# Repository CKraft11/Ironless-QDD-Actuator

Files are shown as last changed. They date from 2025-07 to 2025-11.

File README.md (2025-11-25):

# Ironless-QDD-Actuator

## Overview

The Ironless-QDD-Actuator is a low-cost, high-torque, fully 3D-printed quasi-direct-drive actuator for robotics projects. Using a Halbach array for an ironless rotor and a 3D-printed cycloidal planetary gearbox, it delivers up to 29.4Nm of holding torque for \~$70 (with controller). All custom parts are 3D-printable, making it ideal for makers and hobbyists.

### Key Features

- **Low Cost**: \~$40 (actuator), \~$70 (with controller)
- **High Torque**: 29.4Nm holding torque
- **Fully 3D-Printed**: No machining required
- **Ironless Rotor**: Halbach array for high efficiency
- **Zero Backlash**: Cycloidal gearbox for precision

## Documentation

For detailed design, assembly, and testing info, see my blog post:\
https://cadenkraft.com/ironless-cycloidal-planetary-actuator/

## Repository Contents

- CAD files for entire actuator
- FEMM simulation files
- Bill of Materials (BOM)
- ODrive configuration for MKS X Drive

## Assembly Tips

- USE ENGINEERING PLASTICS! (PA6-GF, PA6-CF, PET-CF, etc) Using PLA is tempting but the rotor will definilty creep due to the magnetic forces.
- Rotor specifically needs to be printed @ 100% infill using a high stiffness plastic with low creep
- Using "CF-Core" filaments for the gears is untested but should work amazingly for having the smooth non abrasive plastic on the outside but still having the stiff carbon additives for strength
- M3 Tap is needed for assembling the planet carrier
- Lithium grease should be used inside the gearbox assembly

## License

MIT License

Permission is hereby granted, free of charge, to any person obtaining a copy of this project and associated files to use, copy, modify, merge, publish, distribute, sublicense, and/or sell copies, provided the following notice is included:

Credit: Caden Kraft (GitHub: CKraft11)

## Contributing

Feedback and contributions are welcome! Submit issues or pull requests on GitHub. If you use this actuator, please share your project!

## Git LFS Required

This repository tracks large binary assets (e.g., `.STEP` CAD files and FEMM outputs) with Git Large File Storage (LFS). To clone and receive these files correctly, install Git LFS before cloning.

If you hit LFS bandwidth limits, the full print and CAD files are also mirrored on MakerWorld: https://makerworld.com/en/models/2042262-caden-kraft-s-qdd-cycloidal-planetary-actuator#profileId-2203426

- Install Git LFS:
  - Windows: `winget install Git.GitLFS` or install via Git for Windows installer (enable LFS component)
  - macOS: `brew install git-lfs`
  - Linux: `sudo apt-get install git-lfs` (Debian/Ubuntu) or use your distro’s package manager
- Initialize LFS once on your machine: `git lfs install`
- Clone the repo: `git clone https://github.com/CKraft11/Ironless-QDD-Actuator.git`

If you already cloned without LFS and see small pointer files instead of the actual binaries, run:

- Ensure LFS is installed: `git lfs install`
- Fetch LFS content: `git lfs fetch --all`
- Checkout LFS files: `git lfs checkout`
  - If needed to fully rehydrate files: `git rm --cached -r .` then `git reset --hard`

Notes
- You do not need to run `git lfs track` yourself; the repository already contains `.gitattributes` with the correct patterns.
- When contributing changes to large binaries, commit as usual; LFS handles storage automatically once installed.

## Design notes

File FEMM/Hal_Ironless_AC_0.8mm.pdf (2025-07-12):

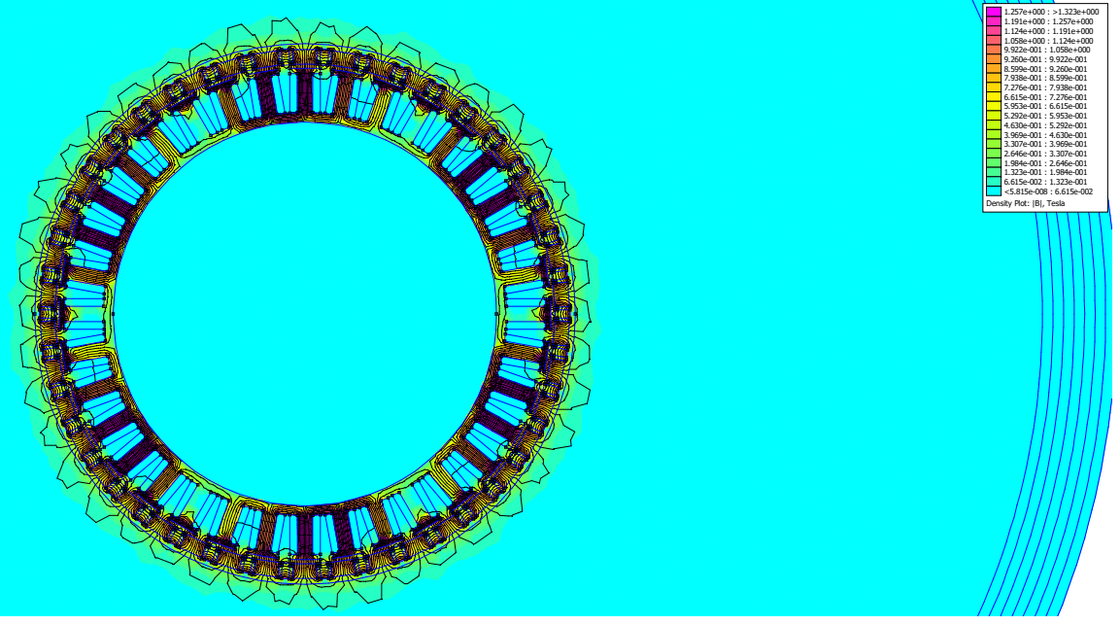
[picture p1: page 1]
Density Plot: |B|, Tesla 1.257e+000 : >1.323e+000 1.191e+000 : 1.257e+000 1.124e+000 : 1.191e+000 1.058e+000 : 1.124e+000 9.922e-001 : 1.058e+000 9.260e-001 : 9.922e-001 8.599e-001 : 9.260e-001 7.938e-001 : 8.599e-001 7.276e-001 : 7.938e-001 6.615e-001 : 7.276e-001 5.953e-001 : 6.615e-001 5.292e-001 : 5.953e-001 4.630e-001 : 5.292e-001 3.969e-001 : 4.630e-001 3.307e-001 : 3.969e-001 2.646e-001 : 3.307e-001 1.984e-001 : 2.646e-001 1.323e-001 : 1.984e-001 6.615e-002 : 1.323e-001 <5.815e-008 : 6.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

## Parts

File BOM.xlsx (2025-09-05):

QDD Actuator BOM |  |  |  |  | Pricing Calculated 4/22/25
Part Name | Part Link | Part Quantity | Cost Per (Part/Gram) | Total Part Cost | Total Cost w/ Controller
6805 Bearing | https://www.amazon.com/dp/B082PYT33D?ref=ppx_yo2ov_dt_b_fed_asin_title&th=1 | 2 | $1.29
6710 Bearing | https://www.amazon.com/dp/B0D6WCB7BP?ref=ppx_yo2ov_dt_b_fed_asin_title | 2 | $2.26 |  | Total Cost w/o Controller
Makerbase MKS XRIVE Mini | https://www.aliexpress.us/item/3256806293928426.html | 1 | $29.99
N52 12x5x3mm | https://www.aliexpress.com/item/3256805740554366.html | 42 | $0.12
N50 1/2 x 1/8 x 1/16in | https://www.magnet4sale.com/n50-1-2x1-8x1-16-neodymium-rare-earth-block-magnet/ | 42 | $0.14
0.4mm Enameled Magnet Wire | https://www.aliexpress.us/item/3256801263693830.html | 60 | $0.02
10010 Stator | https://www.aliexpress.us/item/3256804196417649.html | 1 | $17.63
5x12mm Pin | https://www.aliexpress.us/item/2255800287548941.html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 | 3 | $0.28
M2.5x12mm Countersunk | https://www.aliexpress.us/item/2251832781782755.html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 | 20 | $0.03
M2.5xL4xOD3.5 | https://www.aliexpress.us/item/3256805885174058.html | 7 | $0.03
M3xL4xOD4.2 Brass Insert | https://www.aliexpress.us/item/3256805885174058.html | 14 | $0.03
M4xL4xOD5 Brass Insert | https://www.aliexpress.us/item/3256805885174058.html | 15 | $0.03
M4x25mm Shoulder Bolt | https://www.aliexpress.us/item/3256807139256917.html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 | 1 | $0.53
M2 Locknut | https://www.aliexpress.us/item/2251832612458814.html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 | 4 | $0.06
M3x6mm | https://www.aliexpress.us/item/3256803988371203.html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 | 8 | $0.04
M4 Locknut | https://www.aliexpress.us/item/2251832612458814.html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 | 1 | $0.04
M2x25mm | https://www.aliexpress.us/item/2251832782168715.html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 | 4 | $0.03
5x14x5mm Bearing | https://www.aliexpress.us/item/3256807482131308.html | 6 | $0.32

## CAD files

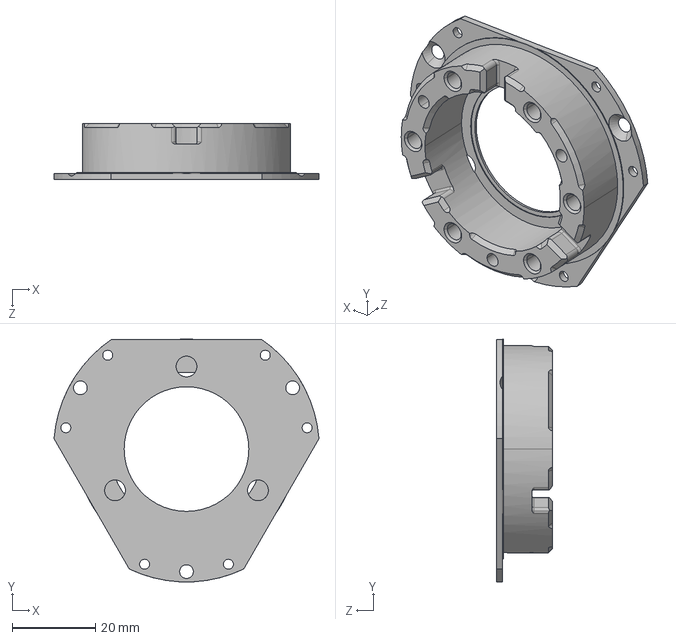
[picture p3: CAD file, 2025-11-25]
CAD/Print_Files/1x_carrier_bottom_output.STEP
63.8 x 58.5 x 13.5 mm

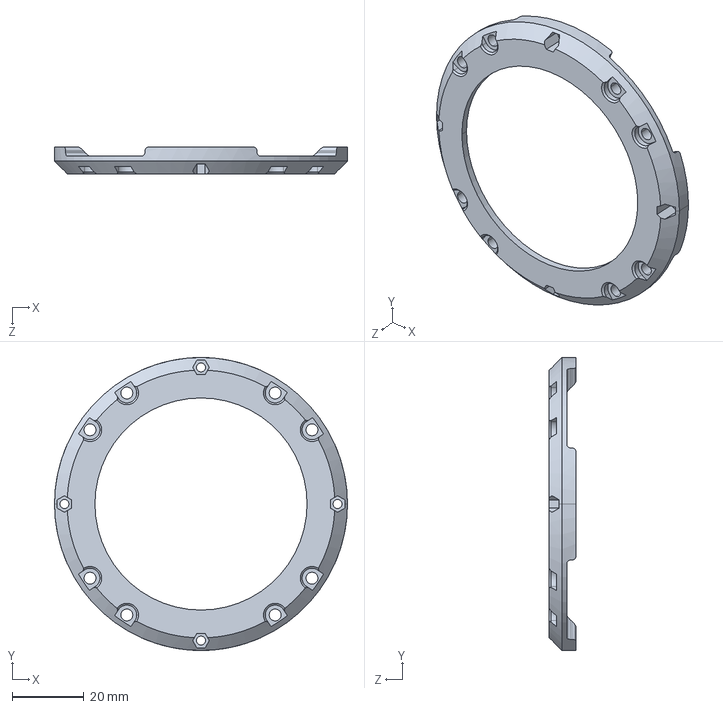
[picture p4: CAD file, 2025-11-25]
CAD/Print_Files/1x_gearbox_top.STEP
81.5 x 81.5 x 7.40 mm

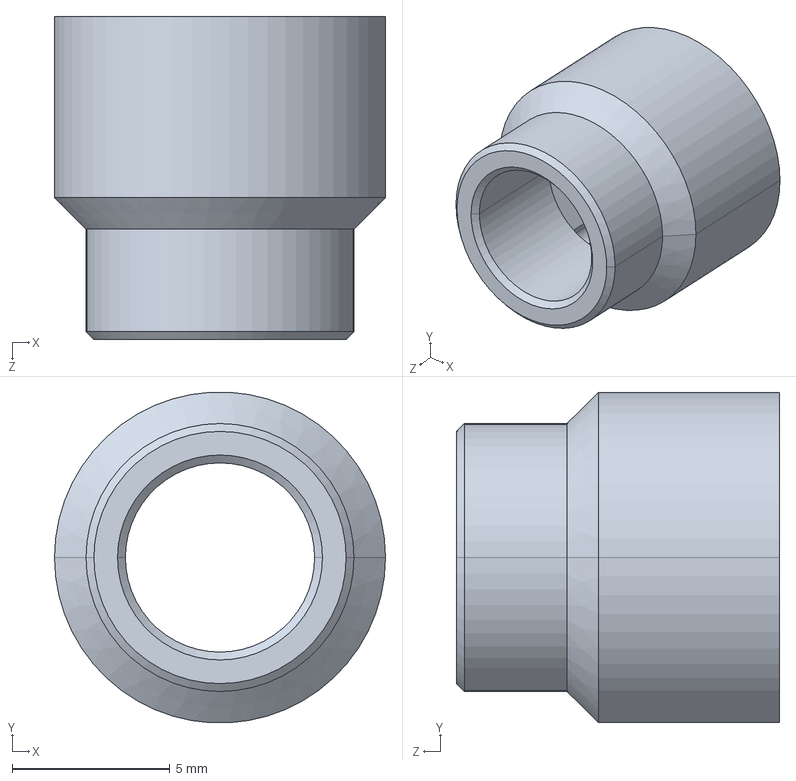
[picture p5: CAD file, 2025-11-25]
CAD/Print_Files/1x_hal_magnet_holder.STEP
10.5 x 10.5 x 10.2 mm

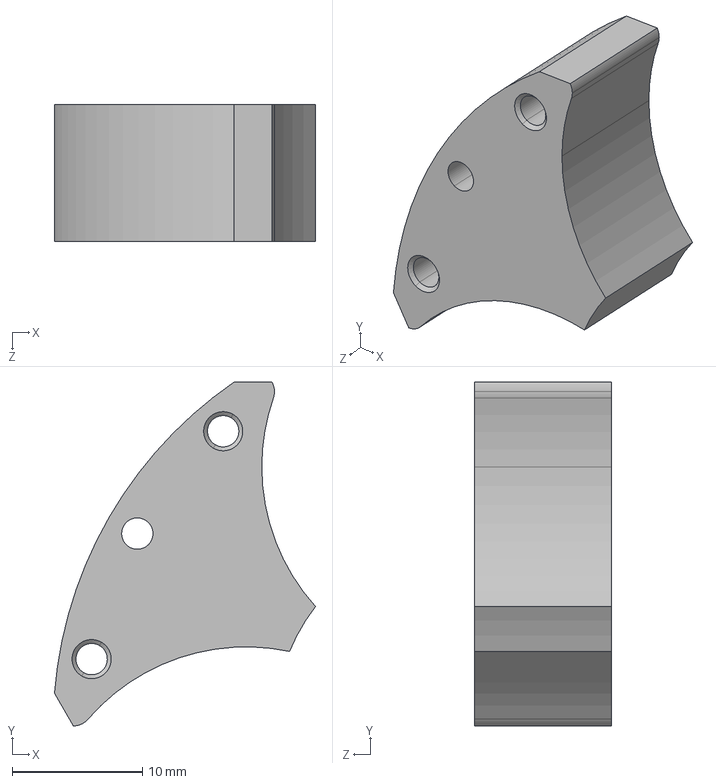
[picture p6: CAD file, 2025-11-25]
CAD/Print_Files/3x_carrier_spacer.STEP
20.0 x 26.4 x 10.5 mm

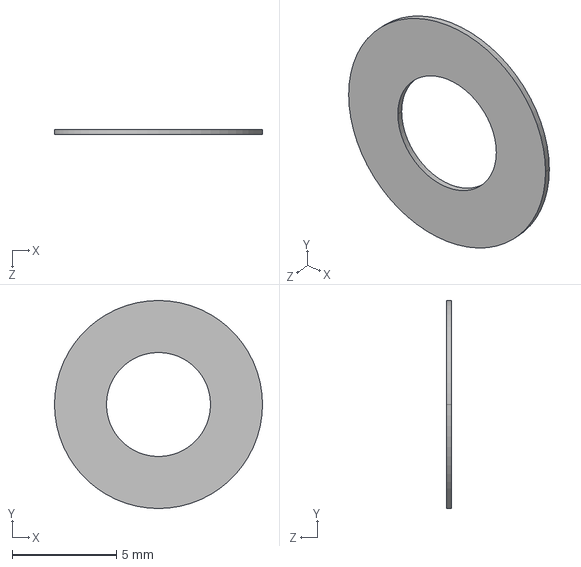
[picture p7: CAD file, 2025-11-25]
CAD/Print_Files/6x_planet_pin_spacer.STEP
10.0 x 10.0 x 0.25 mm

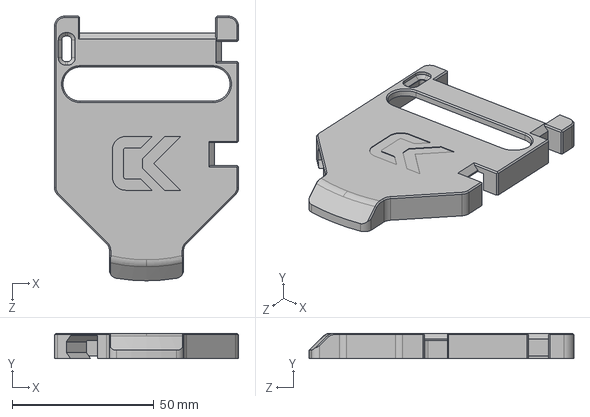
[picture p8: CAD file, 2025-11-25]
CAD/Print_Files/1x_controller_case.STEP
65.0 x 9.00 x 93.5 mm

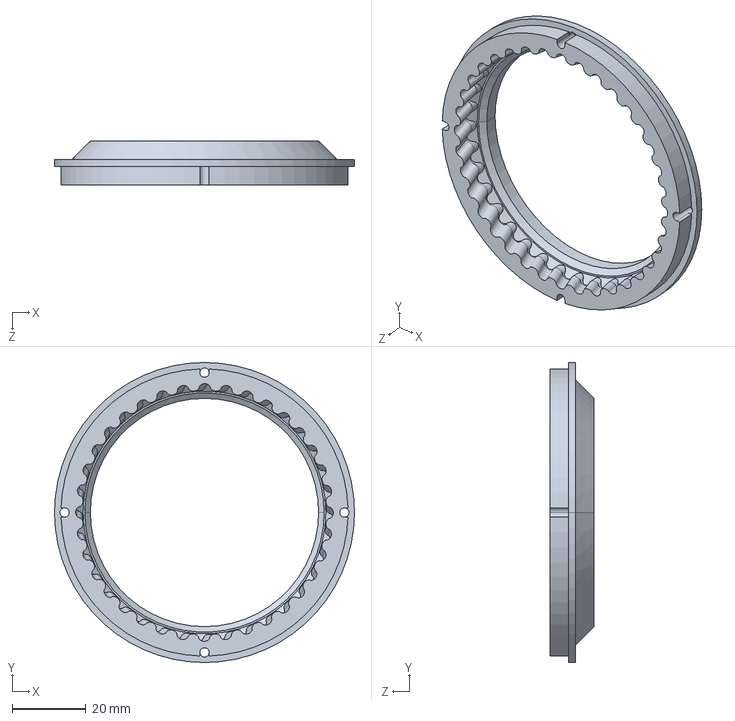
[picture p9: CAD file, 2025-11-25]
CAD/Print_Files/1x_ring_gear_bottom.STEP
81.5 x 81.5 x 12.0 mm

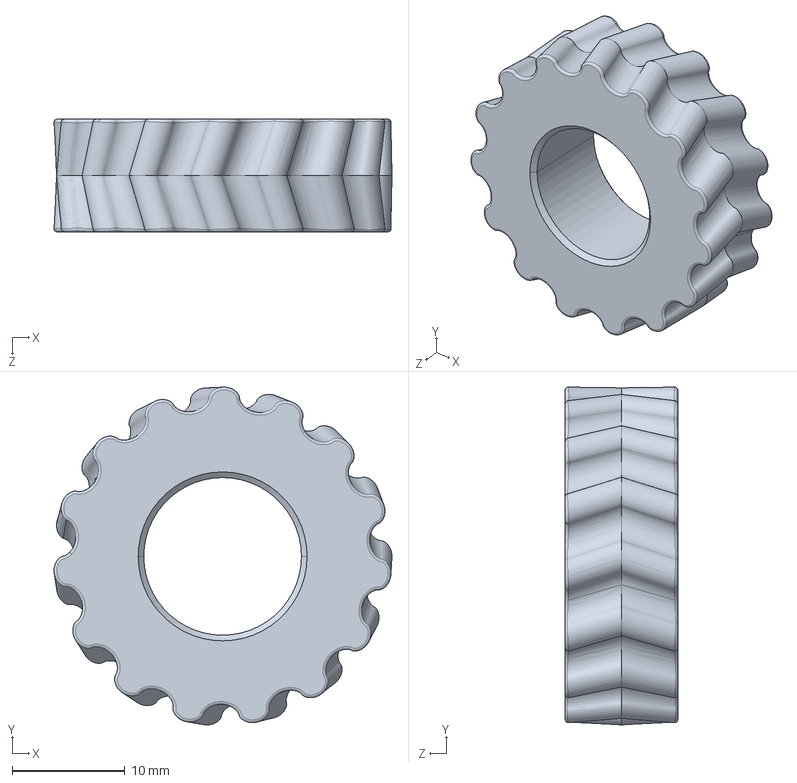
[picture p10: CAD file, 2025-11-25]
CAD/Print_Files/3x_planet_gear.STEP
30.0 x 30.0 x 10.0 mm

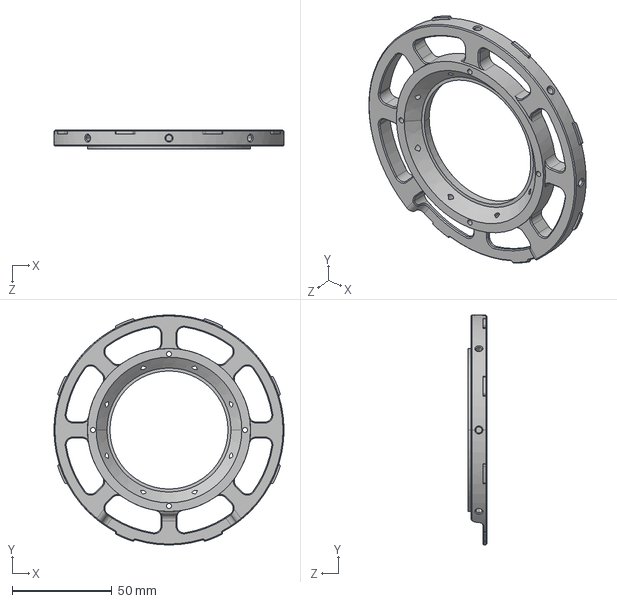
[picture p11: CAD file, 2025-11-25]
CAD/Print_Files/1x_gearbox_bottom.STEP
115.0 x 115.0 x 9.40 mm

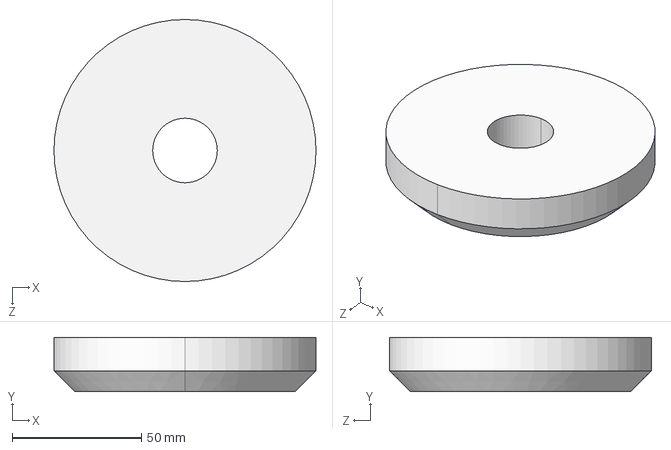
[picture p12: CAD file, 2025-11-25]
CAD/Print_Files/1x_rotor_magnet_glue_fixture.STEP
101.4 x 21.0 x 101.4 mm

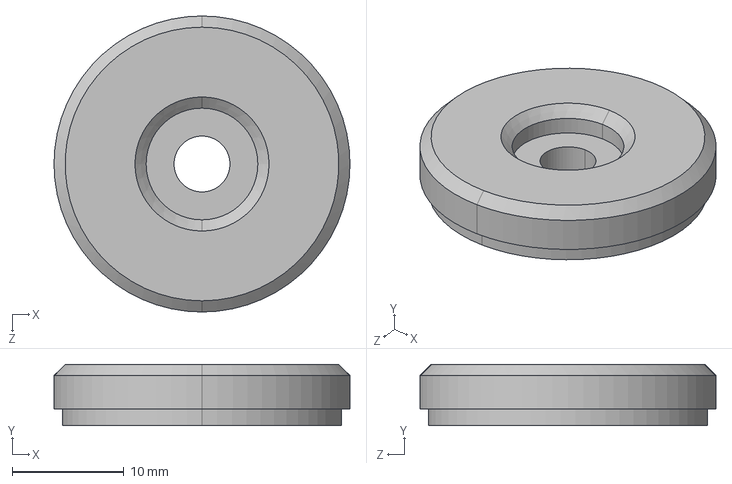
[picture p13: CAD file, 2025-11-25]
CAD/Print_Files/1x_rotor_endcap.STEP
26.5 x 5.50 x 26.5 mm

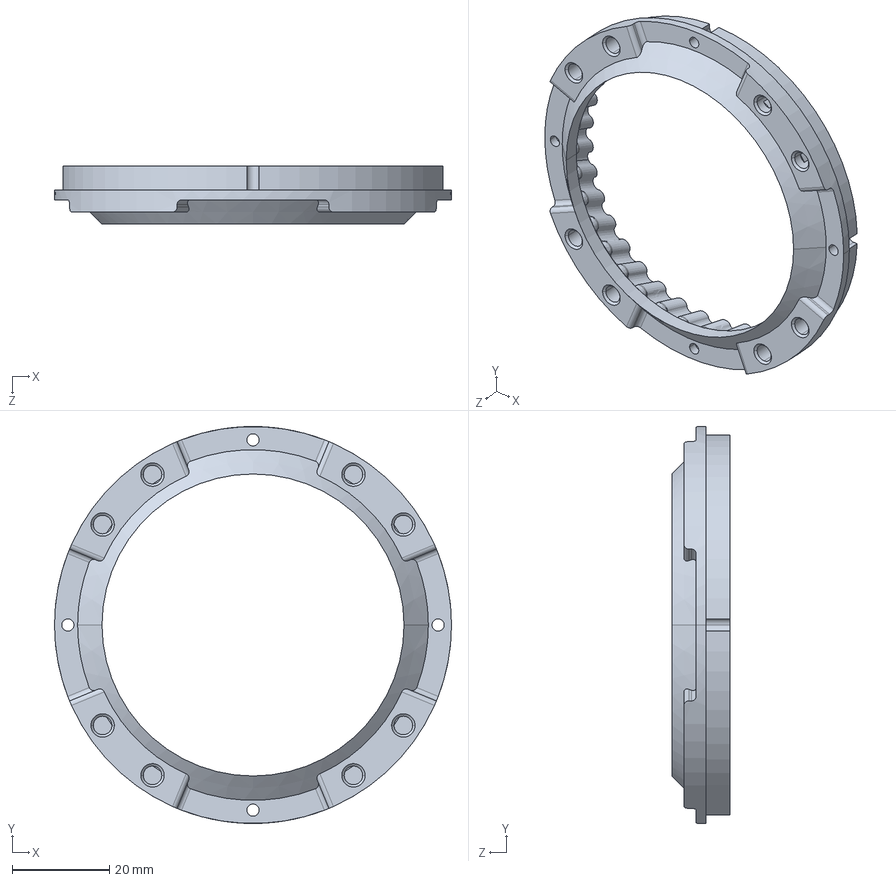
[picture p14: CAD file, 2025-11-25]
CAD/Print_Files/1x_ring_gear_top.STEP
81.5 x 81.5 x 12.0 mm

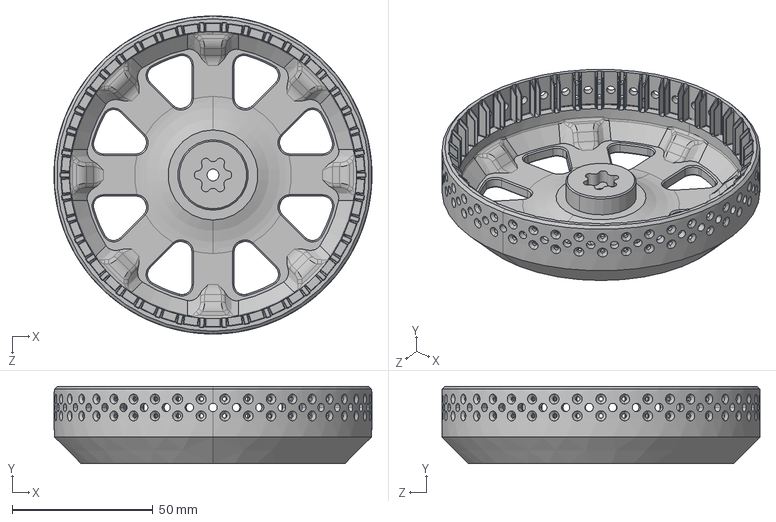
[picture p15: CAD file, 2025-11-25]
CAD/Print_Files/1x_rotor.STEP
113.0 x 27.5 x 113.0 mm

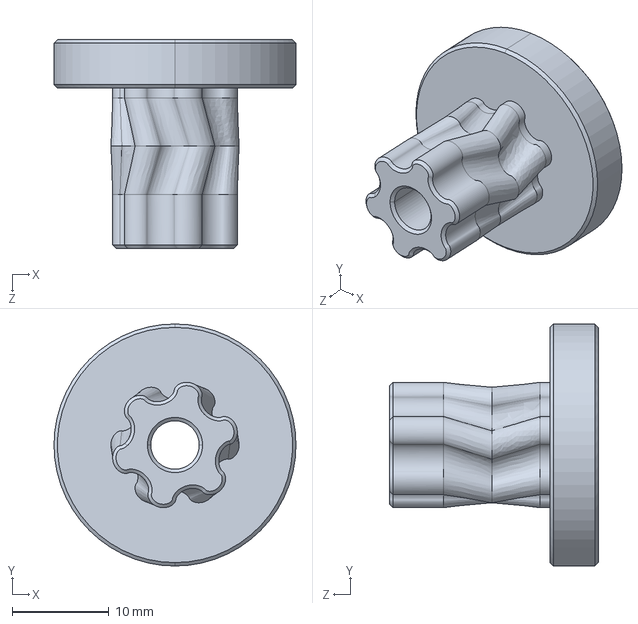
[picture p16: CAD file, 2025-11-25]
CAD/Print_Files/1x_sun_gear.STEP
25.0 x 25.0 x 21.6 mm

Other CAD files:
CAD/actuator.STEP
CAD/Print_Files/1x_carrier_top_cover.STEP
CAD/Print_Files/1x_outer_case.STEP

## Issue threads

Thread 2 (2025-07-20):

Alternative magnet sizing / relevance and/or other providers

alexbarcelo, 2025-07-20:
The project is awesome, very detailed and gives clear steps and clear directions. I am eager to jump into it.

However, I realized that there are two different magnet sizings and one of them cannot longer be found on AliExpress while the other is a US provider that might be challenging to order from.

Looking into alternatives, I found a lot of 20x#x# magnet sizing and some 15x#x#. Virtually no 12x#x# sizing found online (the one this project asks for). I haven't found any listing that has the exact same other two dimensions (I was thinking on a possible Z scaling and using longer magnets, but that can only be done with exact match on the other two dimensions).

Does anybody know of providers that stock the dimensions in the BOM? Alternatively, how easy is it (and how critical on the performance of the motor is) to retrofit/shoehorn other magnets? Maybe some 10x#x# could fit in? However, I still haven't found an exact match on the other dimensions, and those magnet might be too small, I don't know.

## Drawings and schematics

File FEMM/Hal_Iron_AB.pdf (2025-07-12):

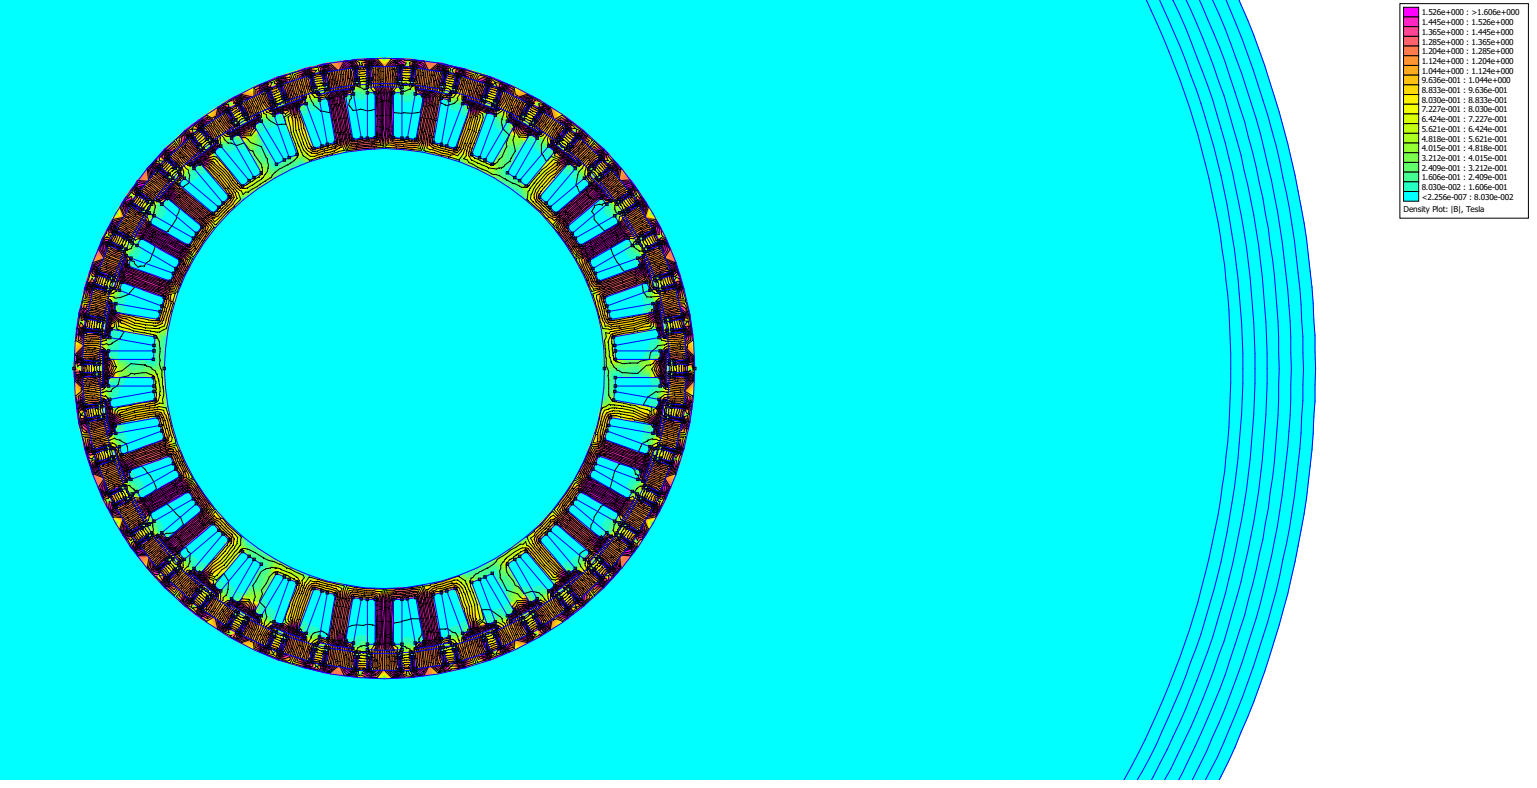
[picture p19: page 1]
Density Plot: |B|, Tesla 1.526e+000 : >1.606e+000 1.445e+000 : 1.526e+000 1.365e+000 : 1.445e+000 1.285e+000 : 1.365e+000 1.204e+000 : 1.285e+000 1.124e+000 : 1.204e+000 1.044e+000 : 1.124e+000 9.636e-001 : 1.044e+000 8.833e-001 : 9.636e-001 8.030e-001 : 8.833e-001 7.227e-001 : 8.030e-001 6.424e-001 : 7.227e-001 5.621e-001 : 6.424e-001 4.818e-001 : 5.621e-001 4.015e-001 : 4.818e-001 3.212e-001 : 4.015e-001 2.409e-001 : 3.212e-001 1.606e-001 : 2.409e-001 8.030e-002 : 1.606e-001 <2.256e-007 : 8.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

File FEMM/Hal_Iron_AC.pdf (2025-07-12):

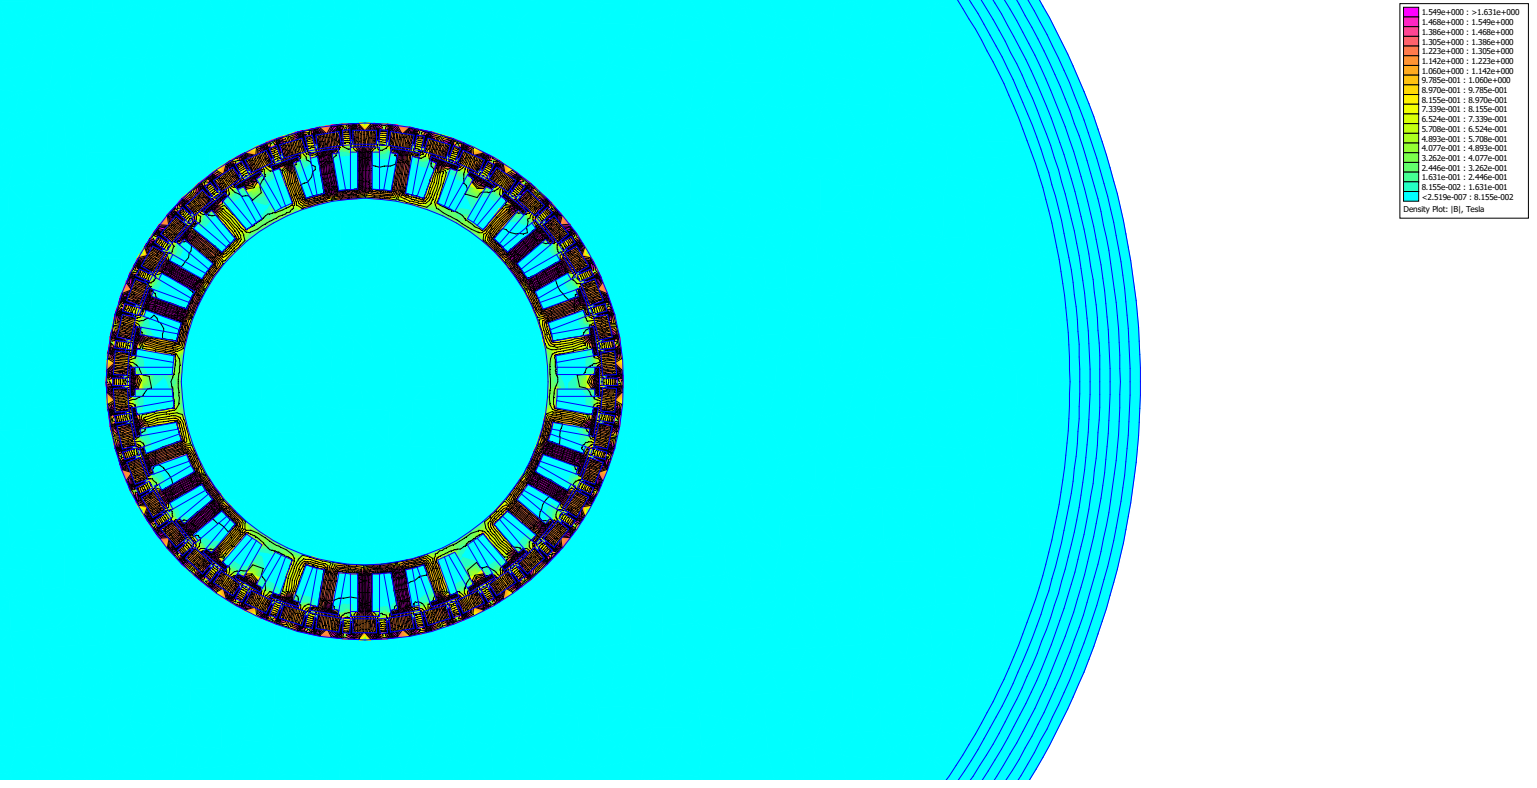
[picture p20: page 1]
Density Plot: |B|, Tesla 1.549e+000 : >1.631e+000 1.468e+000 : 1.549e+000 1.386e+000 : 1.468e+000 1.305e+000 : 1.386e+000 1.223e+000 : 1.305e+000 1.142e+000 : 1.223e+000 1.060e+000 : 1.142e+000 9.785e-001 : 1.060e+000 8.970e-001 : 9.785e-001 8.155e-001 : 8.970e-001 7.339e-001 : 8.155e-001 6.524e-001 : 7.339e-001 5.708e-001 : 6.524e-001 4.893e-001 : 5.708e-001 4.077e-001 : 4.893e-001 3.262e-001 : 4.077e-001 2.446e-001 : 3.262e-001 1.631e-001 : 2.446e-001 8.155e-002 : 1.631e-001 <2.519e-007 : 8.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

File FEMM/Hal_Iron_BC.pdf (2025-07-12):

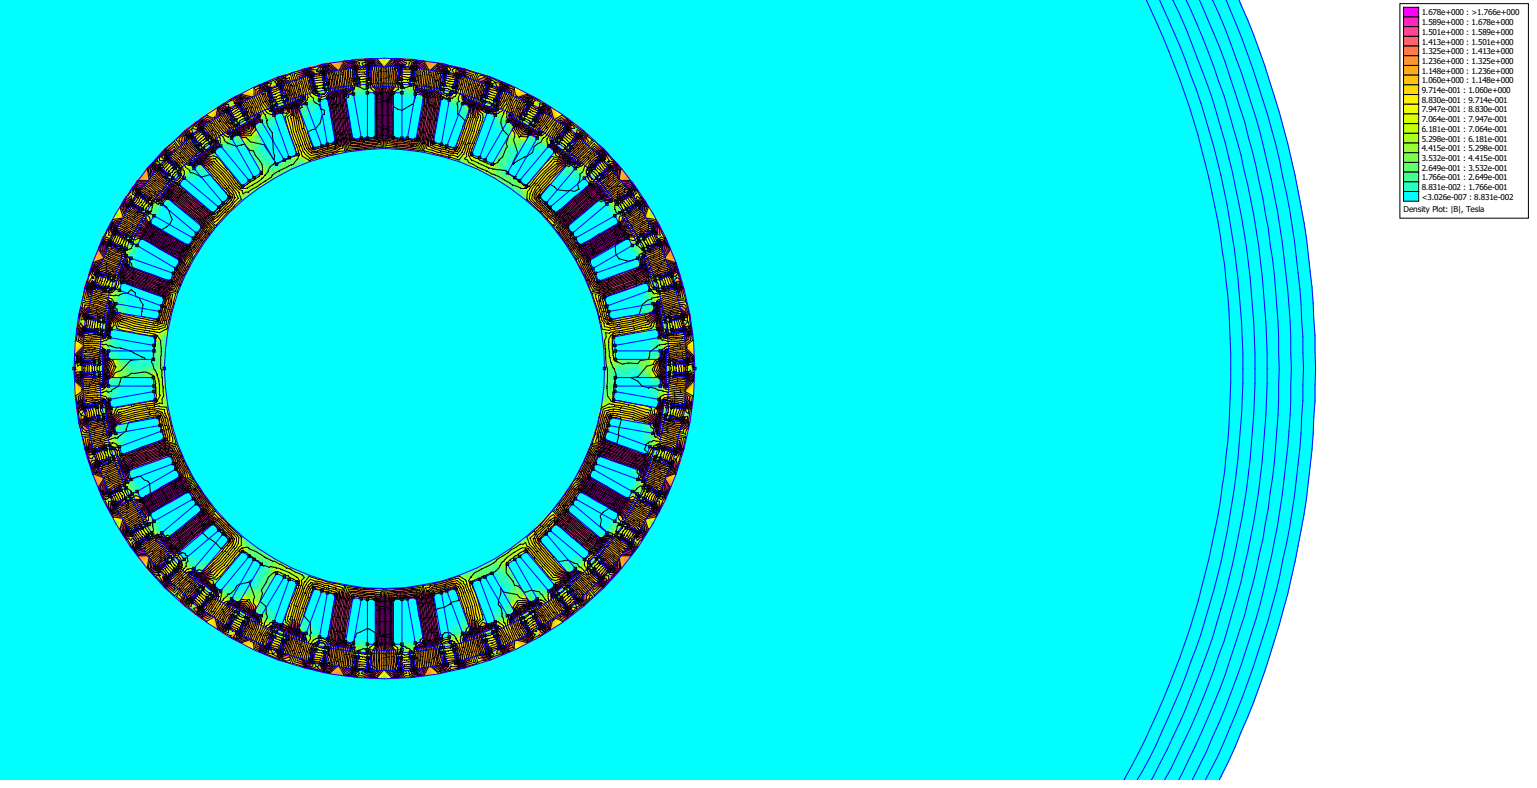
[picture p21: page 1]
Density Plot: |B|, Tesla 1.678e+000 : >1.766e+000 1.589e+000 : 1.678e+000 1.501e+000 : 1.589e+000 1.413e+000 : 1.501e+000 1.325e+000 : 1.413e+000 1.236e+000 : 1.325e+000 1.148e+000 : 1.236e+000 1.060e+000 : 1.148e+000 9.714e-001 : 1.060e+000 8.830e-001 : 9.714e-001 7.947e-001 : 8.830e-001 7.064e-001 : 7.947e-001 6.181e-001 : 7.064e-001 5.298e-001 : 6.181e-001 4.415e-001 : 5.298e-001 3.532e-001 : 4.415e-001 2.649e-001 : 3.532e-001 1.766e-001 : 2.649e-001 8.831e-002 : 1.766e-001 <3.026e-007 : 8.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

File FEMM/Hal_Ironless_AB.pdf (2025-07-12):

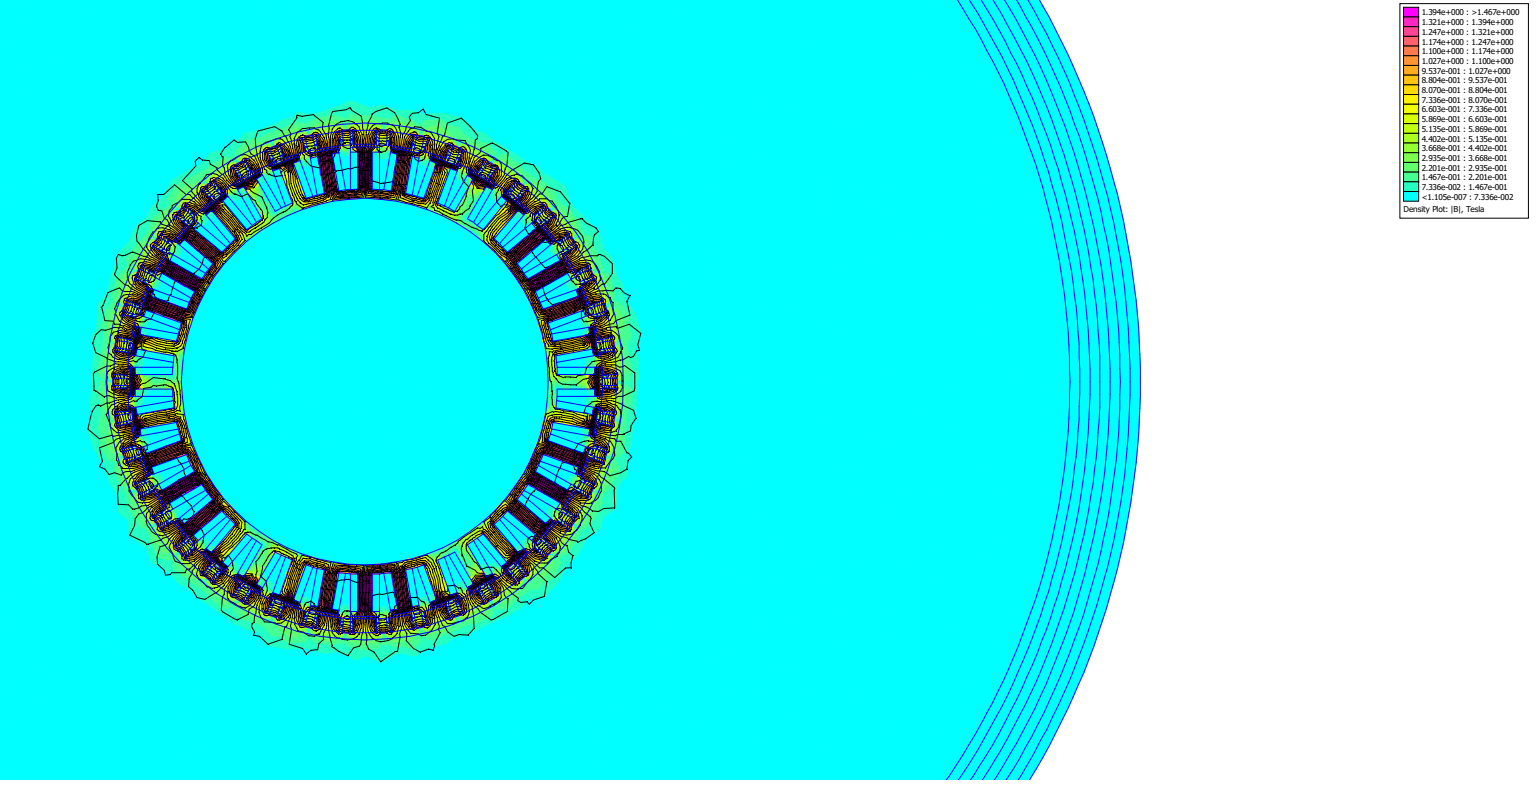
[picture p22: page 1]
Density Plot: |B|, Tesla 1.394e+000 : >1.467e+000 1.321e+000 : 1.394e+000 1.247e+000 : 1.321e+000 1.174e+000 : 1.247e+000 1.100e+000 : 1.174e+000 1.027e+000 : 1.100e+000 9.537e-001 : 1.027e+000 8.804e-001 : 9.537e-001 8.070e-001 : 8.804e-001 7.336e-001 : 8.070e-001 6.603e-001 : 7.336e-001 5.869e-001 : 6.603e-001 5.135e-001 : 5.869e-001 4.402e-001 : 5.135e-001 3.668e-001 : 4.402e-001 2.935e-001 : 3.668e-001 2.201e-001 : 2.935e-001 1.467e-001 : 2.201e-001 7.336e-002 : 1.467e-001 <1.105e-007 : 7.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

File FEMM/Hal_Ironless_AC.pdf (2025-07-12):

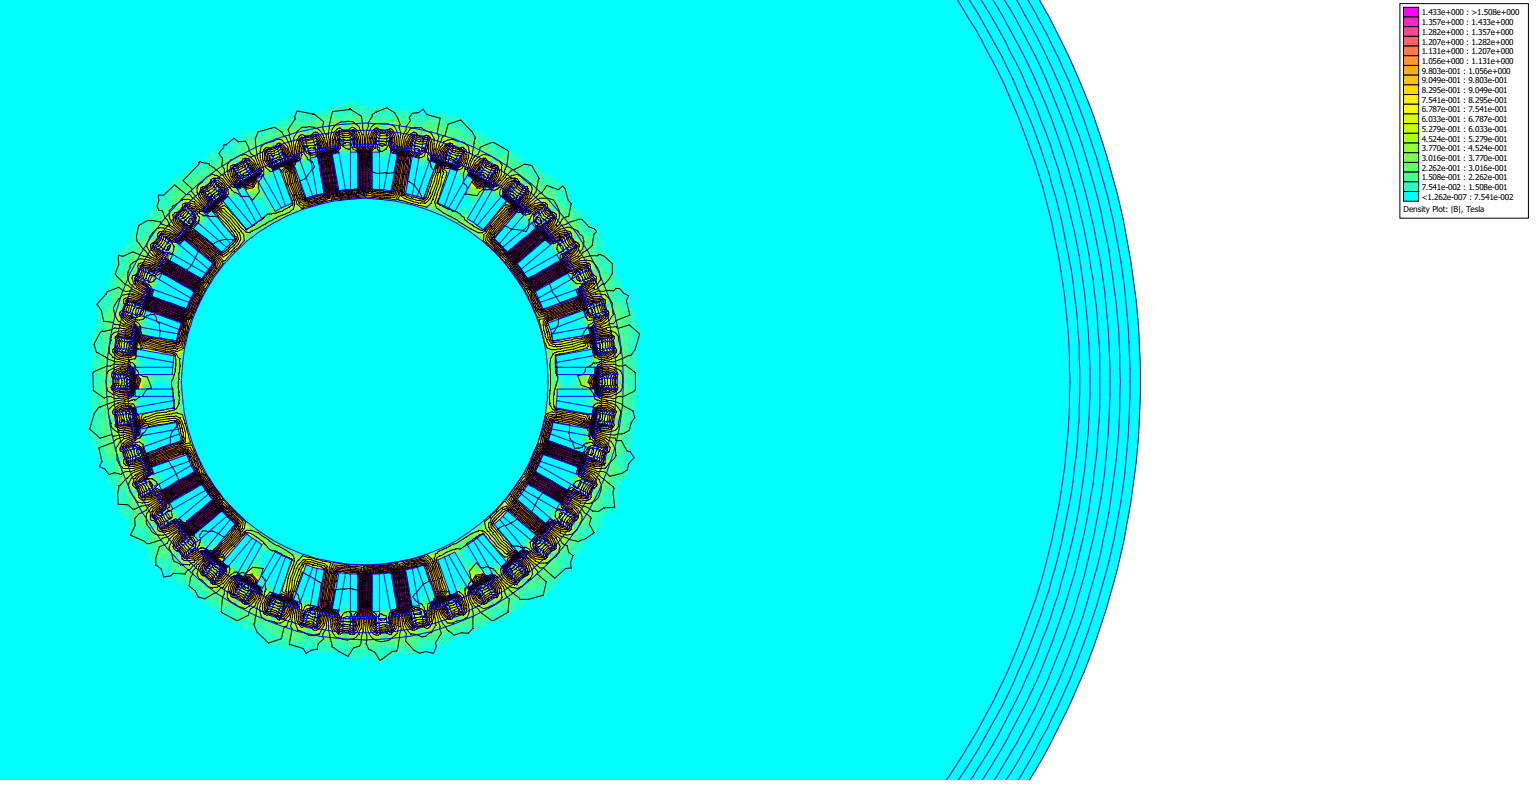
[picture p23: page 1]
Density Plot: |B|, Tesla 1.433e+000 : >1.508e+000 1.357e+000 : 1.433e+000 1.282e+000 : 1.357e+000 1.207e+000 : 1.282e+000 1.131e+000 : 1.207e+000 1.056e+000 : 1.131e+000 9.803e-001 : 1.056e+000 9.049e-001 : 9.803e-001 8.295e-001 : 9.049e-001 7.541e-001 : 8.295e-001 6.787e-001 : 7.541e-001 6.033e-001 : 6.787e-001 5.279e-001 : 6.033e-001 4.524e-001 : 5.279e-001 3.770e-001 : 4.524e-001 3.016e-001 : 3.770e-001 2.262e-001 : 3.016e-001 1.508e-001 : 2.262e-001 7.541e-002 : 1.508e-001 <1.262e-007 : 7.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

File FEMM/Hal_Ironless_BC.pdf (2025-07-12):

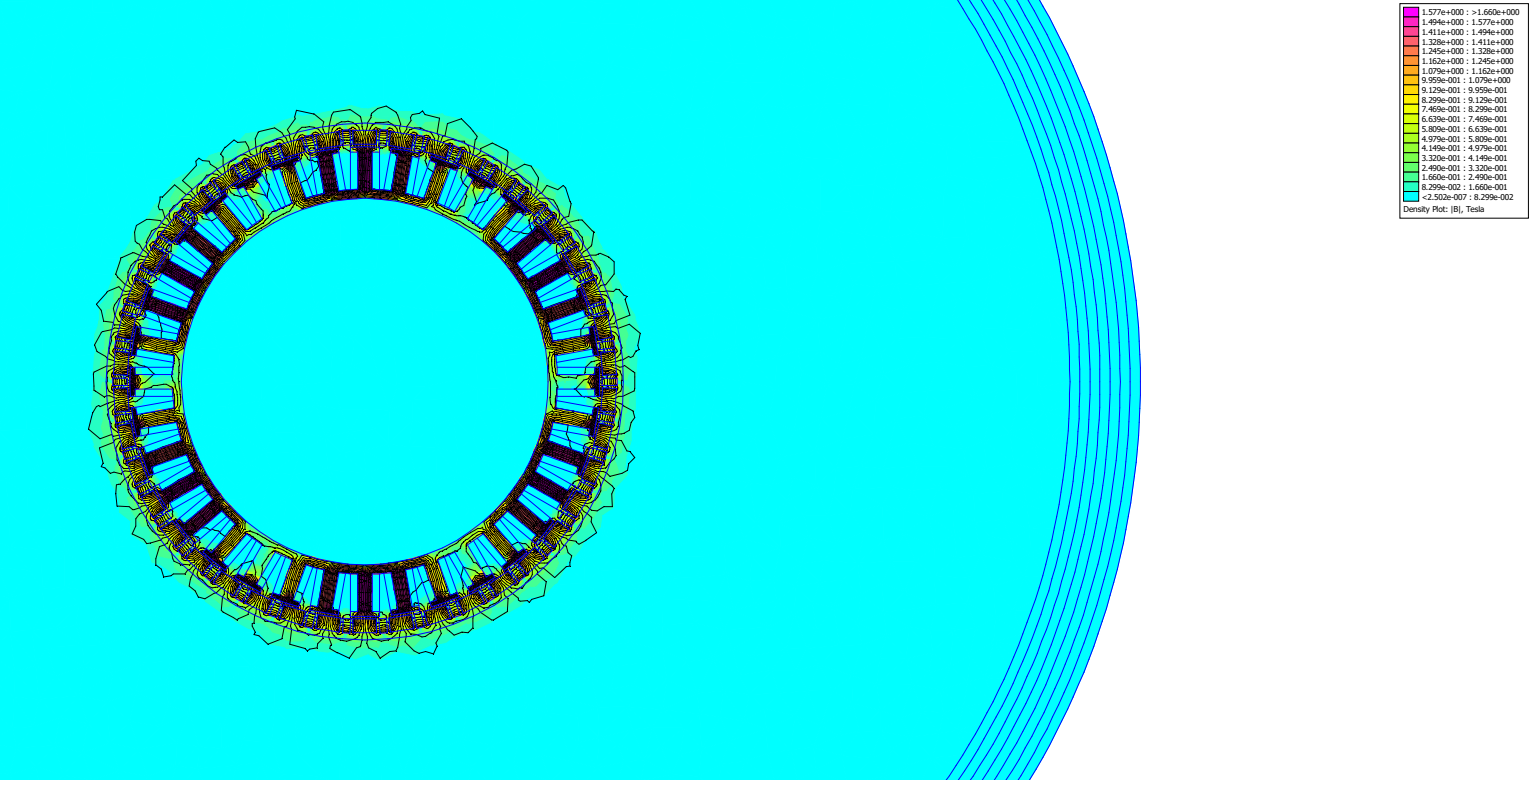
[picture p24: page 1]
Density Plot: |B|, Tesla 1.577e+000 : >1.660e+000 1.494e+000 : 1.577e+000 1.411e+000 : 1.494e+000 1.328e+000 : 1.411e+000 1.245e+000 : 1.328e+000 1.162e+000 : 1.245e+000 1.079e+000 : 1.162e+000 9.959e-001 : 1.079e+000 9.129e-001 : 9.959e-001 8.299e-001 : 9.129e-001 7.469e-001 : 8.299e-001 6.639e-001 : 7.469e-001 5.809e-001 : 6.639e-001 4.979e-001 : 5.809e-001 4.149e-001 : 4.979e-001 3.320e-001 : 4.149e-001 2.490e-001 : 3.320e-001 1.660e-001 : 2.490e-001 8.299e-002 : 1.660e-001 <2.502e-007 : 8.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

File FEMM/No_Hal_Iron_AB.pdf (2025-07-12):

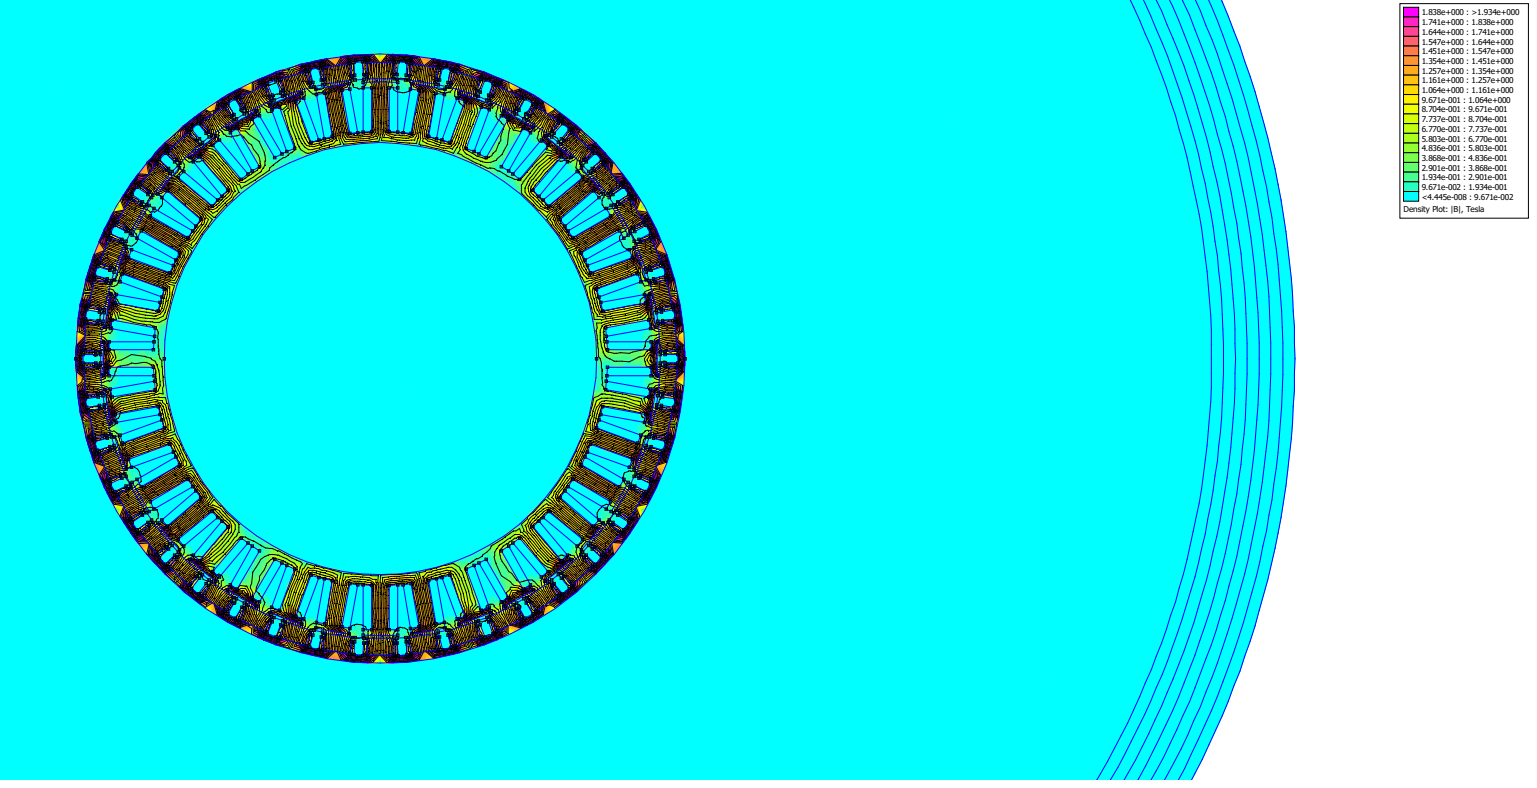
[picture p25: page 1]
Density Plot: |B|, Tesla 1.838e+000 : >1.934e+000 1.741e+000 : 1.838e+000 1.644e+000 : 1.741e+000 1.547e+000 : 1.644e+000 1.451e+000 : 1.547e+000 1.354e+000 : 1.451e+000 1.257e+000 : 1.354e+000 1.161e+000 : 1.257e+000 1.064e+000 : 1.161e+000 9.671e-001 : 1.064e+000 8.704e-001 : 9.671e-001 7.737e-001 : 8.704e-001 6.770e-001 : 7.737e-001 5.803e-001 : 6.770e-001 4.836e-001 : 5.803e-001 3.868e-001 : 4.836e-001 2.901e-001 : 3.868e-001 1.934e-001 : 2.901e-001 9.671e-002 : 1.934e-001 <4.445e-008 : 9.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

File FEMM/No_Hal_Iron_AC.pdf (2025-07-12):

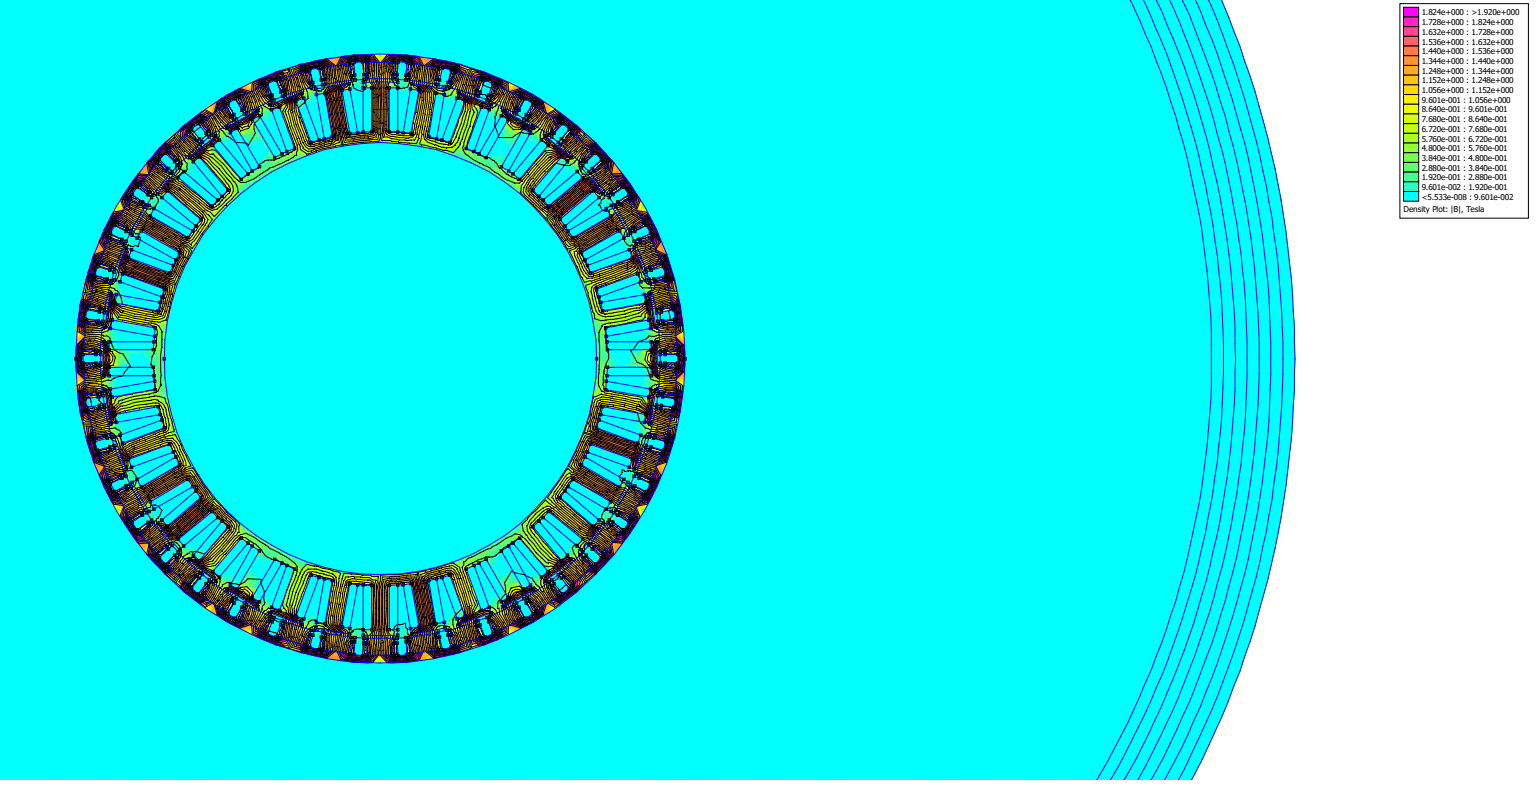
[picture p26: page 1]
Density Plot: |B|, Tesla 1.824e+000 : >1.920e+000 1.728e+000 : 1.824e+000 1.632e+000 : 1.728e+000 1.536e+000 : 1.632e+000 1.440e+000 : 1.536e+000 1.344e+000 : 1.440e+000 1.248e+000 : 1.344e+000 1.152e+000 : 1.248e+000 1.056e+000 : 1.152e+000 9.601e-001 : 1.056e+000 8.640e-001 : 9.601e-001 7.680e-001 : 8.640e-001 6.720e-001 : 7.680e-001 5.760e-001 : 6.720e-001 4.800e-001 : 5.760e-001 3.840e-001 : 4.800e-001 2.880e-001 : 3.840e-001 1.920e-001 : 2.880e-001 9.601e-002 : 1.920e-001 <5.533e-008 : 9.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

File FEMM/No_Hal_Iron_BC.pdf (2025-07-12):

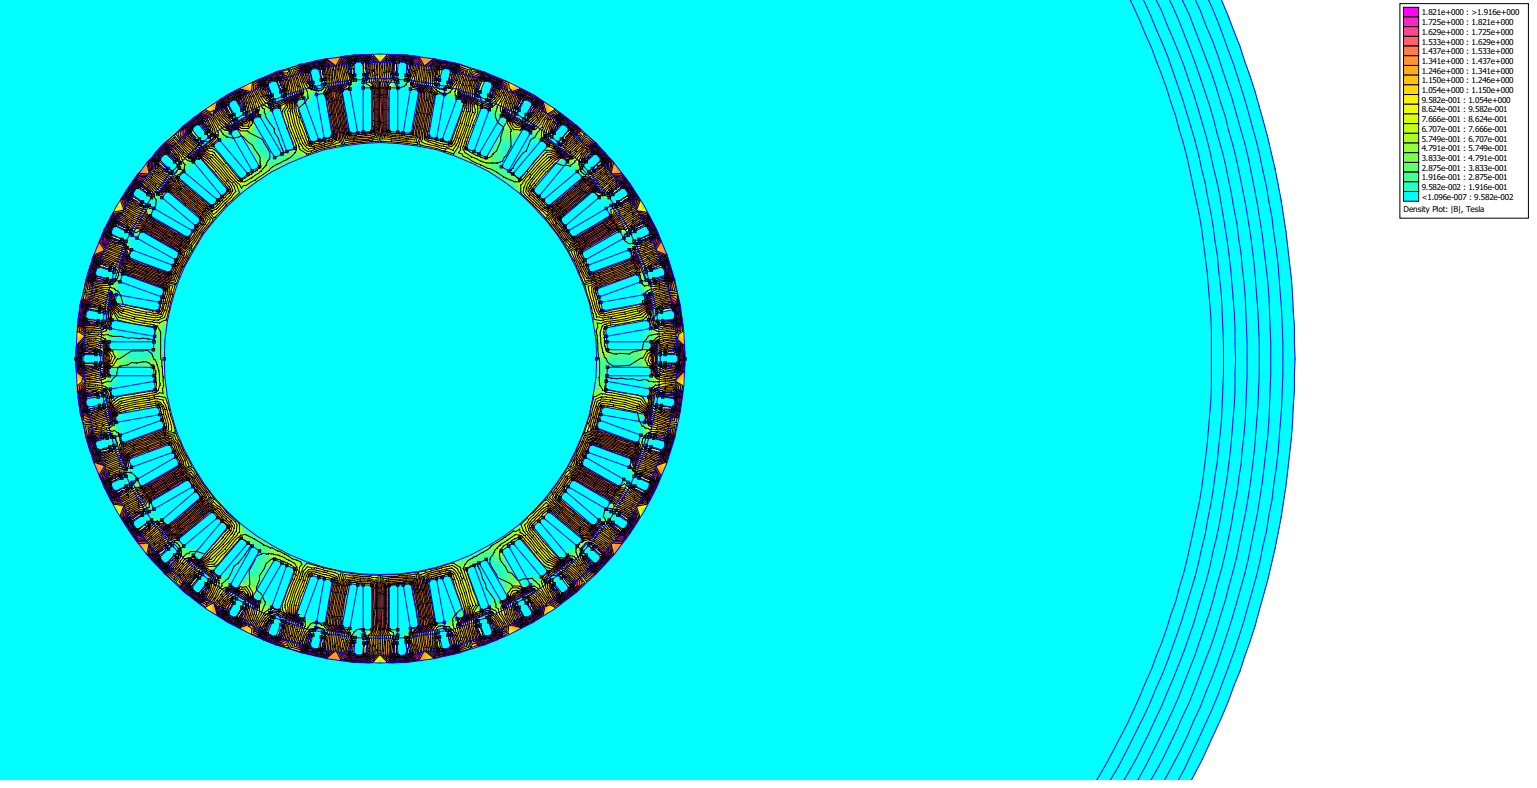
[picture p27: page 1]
Density Plot: |B|, Tesla 1.821e+000 : >1.916e+000 1.725e+000 : 1.821e+000 1.629e+000 : 1.725e+000 1.533e+000 : 1.629e+000 1.437e+000 : 1.533e+000 1.341e+000 : 1.437e+000 1.246e+000 : 1.341e+000 1.150e+000 : 1.246e+000 1.054e+000 : 1.150e+000 9.582e-001 : 1.054e+000 8.624e-001 : 9.582e-001 7.666e-001 : 8.624e-001 6.707e-001 : 7.666e-001 5.749e-001 : 6.707e-001 4.791e-001 : 5.749e-001 3.833e-001 : 4.791e-001 2.875e-001 : 3.833e-001 1.916e-001 : 2.875e-001 9.582e-002 : 1.916e-001 <1.096e-007 : 9.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

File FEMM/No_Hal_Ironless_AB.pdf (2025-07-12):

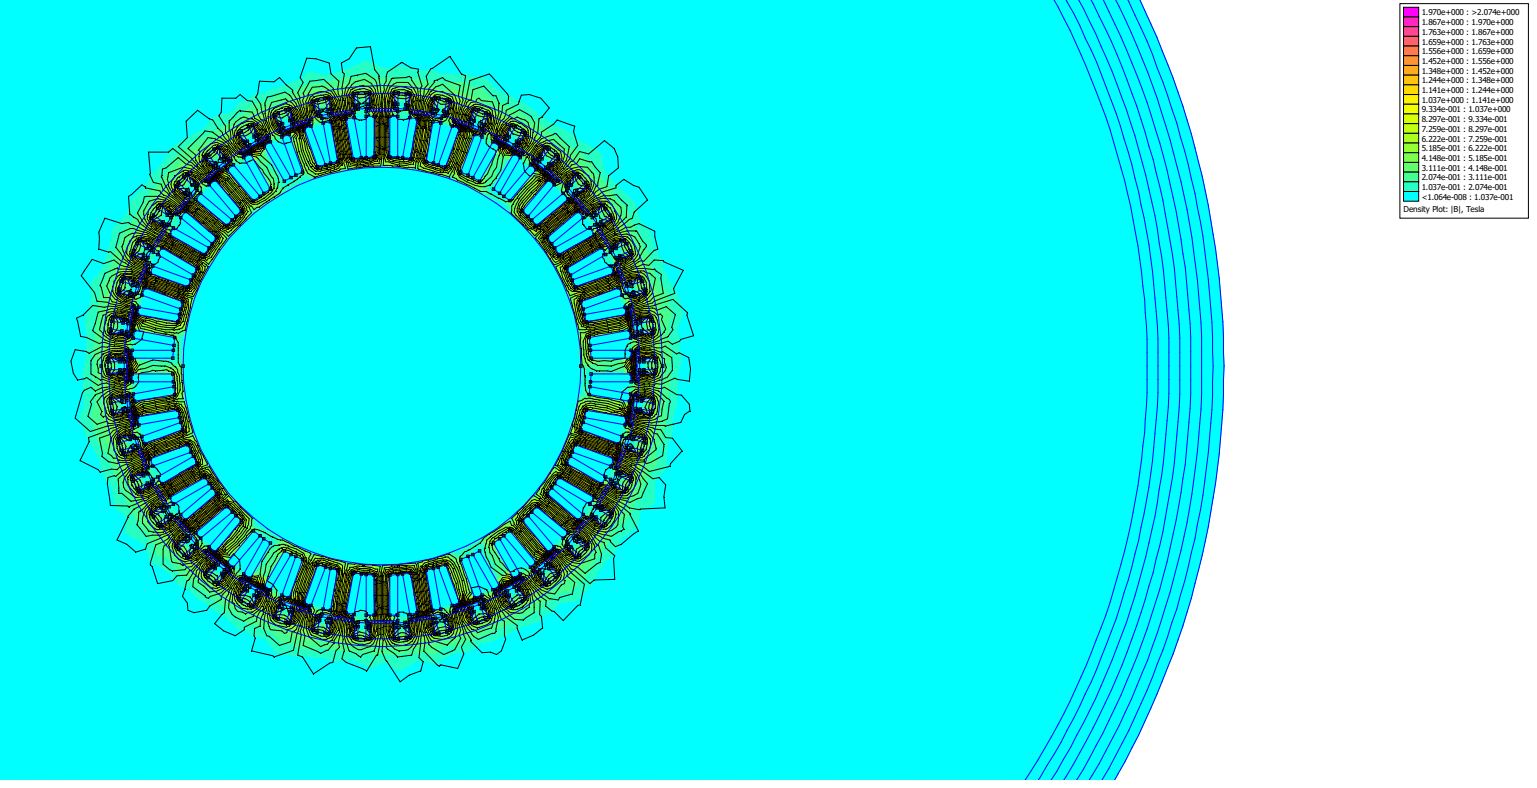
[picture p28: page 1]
Density Plot: |B|, Tesla 1.970e+000 : >2.074e+000 1.867e+000 : 1.970e+000 1.763e+000 : 1.867e+000 1.659e+000 : 1.763e+000 1.556e+000 : 1.659e+000 1.452e+000 : 1.556e+000 1.348e+000 : 1.452e+000 1.244e+000 : 1.348e+000 1.141e+000 : 1.244e+000 1.037e+000 : 1.141e+000 9.334e-001 : 1.037e+000 8.297e-001 : 9.334e-001 7.259e-001 : 8.297e-001 6.222e-001 : 7.259e-001 5.185e-001 : 6.222e-001 4.148e-001 : 5.185e-001 3.111e-001 : 4.148e-001 2.074e-001 : 3.111e-001 1.037e-001 : 2.074e-001 <1.064e-008 : 1.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

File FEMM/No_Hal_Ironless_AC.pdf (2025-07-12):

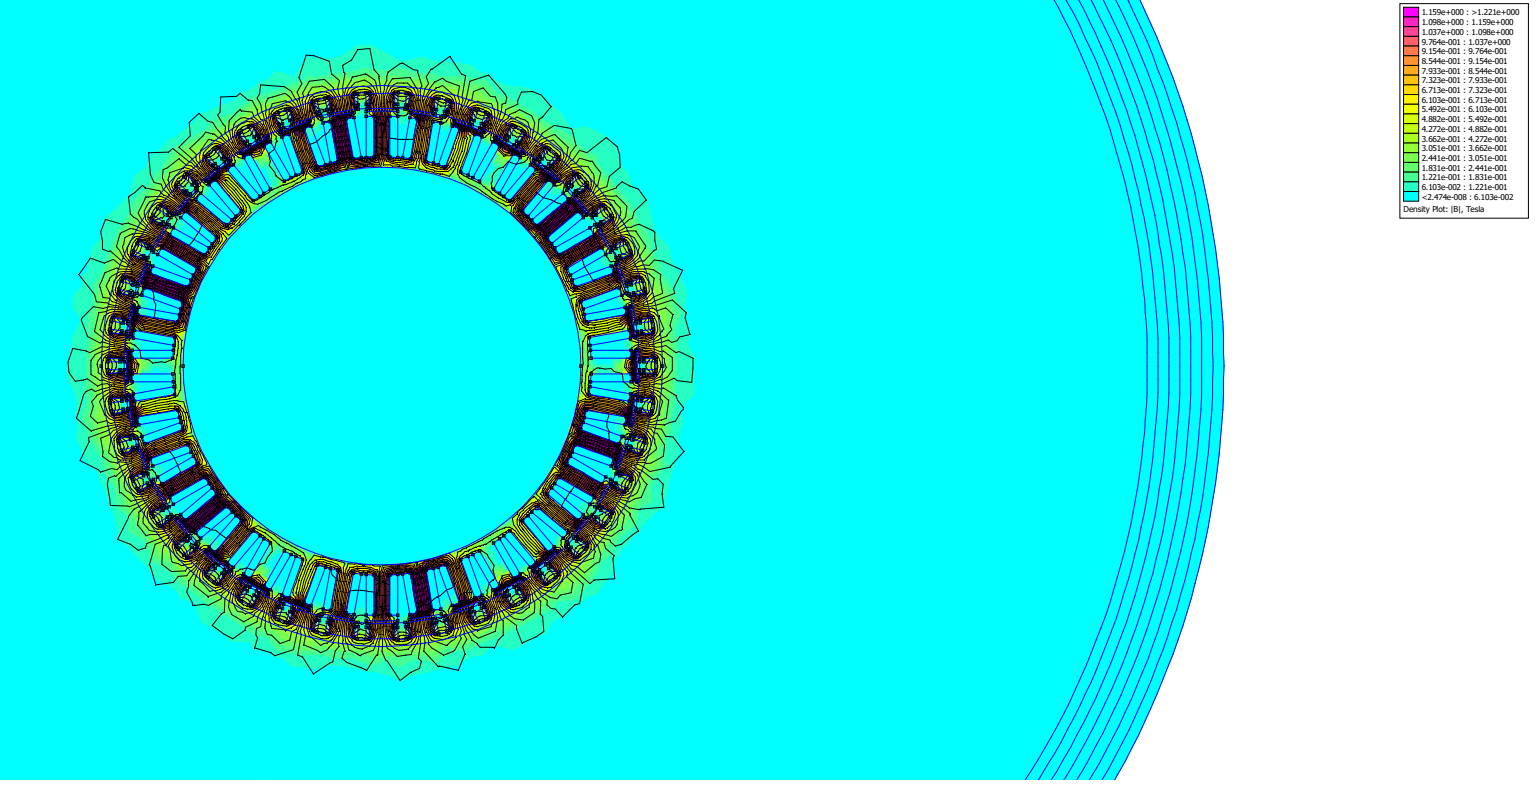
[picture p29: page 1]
Density Plot: |B|, Tesla 1.159e+000 : >1.221e+000 1.098e+000 : 1.159e+000 1.037e+000 : 1.098e+000 9.764e-001 : 1.037e+000 9.154e-001 : 9.764e-001 8.544e-001 : 9.154e-001 7.933e-001 : 8.544e-001 7.323e-001 : 7.933e-001 6.713e-001 : 7.323e-001 6.103e-001 : 6.713e-001 5.492e-001 : 6.103e-001 4.882e-001 : 5.492e-001 4.272e-001 : 4.882e-001 3.662e-001 : 4.272e-001 3.051e-001 : 3.662e-001 2.441e-001 : 3.051e-001 1.831e-001 : 2.441e-001 1.221e-001 : 1.831e-001 6.103e-002 : 1.221e-001 <2.474e-008 : 6.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

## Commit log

2025-09-05 added print files
    [1x_carrier_bottom_output.STEP, 1x_carrier_top_cover.STEP, 1x_controller_case.STEP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]
2025-10-20 Added missing STEP and provided instructions for using git LFS
    [1x_hal_magnet_holder.STEP]
2025-10-20 Added assembly tips to readme
2025-11-25 more lfs troubles
    [1x_carrier_bottom_output.STEP, 1x_carrier_top_cover.STEP, 1x_controller_case.STEP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]
2025-12-01 corrupted actuator.step, reuploading...
    [actuator.STEP]
